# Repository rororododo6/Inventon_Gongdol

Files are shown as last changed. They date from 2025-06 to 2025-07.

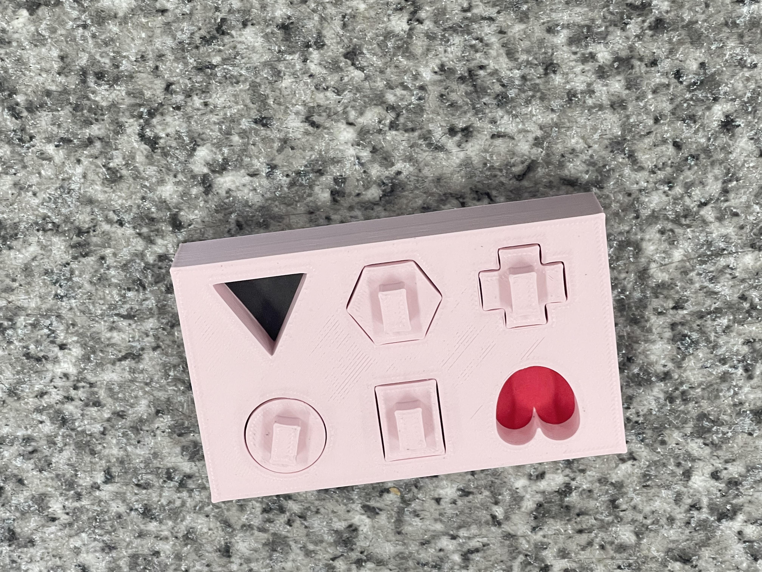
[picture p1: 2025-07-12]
HW/puzzle/AI/my-project/Parrot Puzzle.v2i.yolov11/test/images/KakaoTalk_20250710_180313041_14_jpg.rf.926b0de10124c375c126a7784142336b.jpg

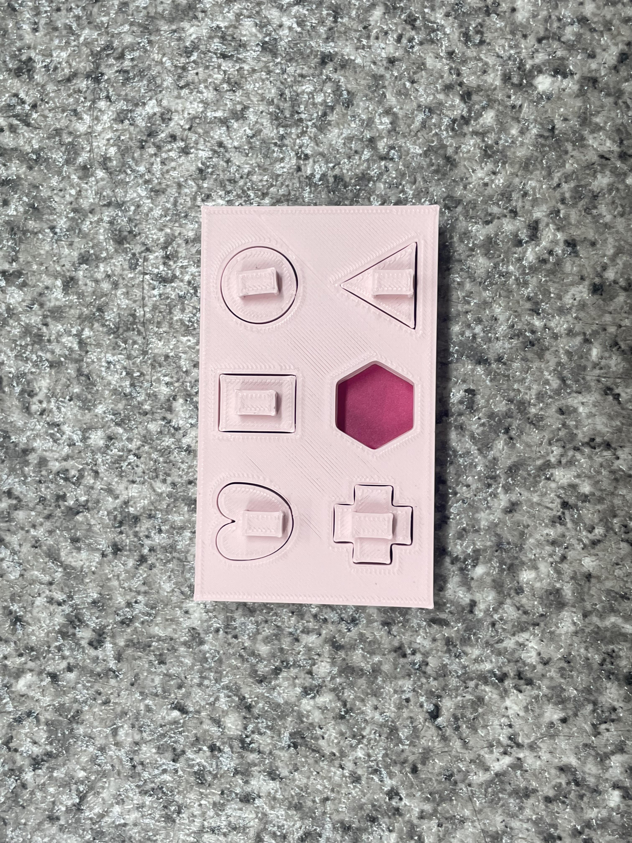
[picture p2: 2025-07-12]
HW/puzzle/AI/my-project/Parrot Puzzle.v2i.yolov11/test/images/KakaoTalk_20250710_180337943_19_jpg.rf.0f06c9184ed237936c7adf1d38ee5073.jpg

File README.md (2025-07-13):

# �� 새장 화장실 자동 청소 시스템

**라즈베리파이 4 + Arduino 기반 AI 새똥 탐지 및 자동 청소 시스템**

YOLO 커스텀 모델을 이용한 새똥 특화 탐지와 누적 방식 청소 시스템입니다.

## 🎯 주요 기능

### 🔍 AI 새똥 탐지 (누적 방식)
- **YOLO 커스텀 모델**: 새똥 특화 훈련 모델 (train63/weights/best.pt)
- **누적 탐지**: 새똥 영역을 메모리에 누적 저장
- **중복 제거**: IoU 계산으로 겹치는 영역 자동 병합
- **임계값**: 카메라 픽셀 면적의 **50%** 누적 시 청소 시작

### 🧹 3단계 자동 청소 시스템
- **1단계**: SG90 서보모터 모래 밀어내기 (0°↔90°, 20회)
- **2단계**: 28BYJ-48 스테핑 모터 똥 치우기 (3바퀴 회전)
- **3단계**: 원위치 복귀 및 누적 영역 데이터 초기화

### 🗑️ 스마트 청소 관리
- **청소 카운터**: 최대 100회 청소 제한
- **상태 모니터링**: 실시간 누적 영역 개수, 커버리지 비율 표시
- **경고 시스템**: 30%, 50% 임계값별 알림
- **안전 시스템**: 긴급 정지 버튼, 상태 LED, 알림 부저

### 📊 실시간 모니터링
- **환경 데이터**: DHT11 온습도 센서
- **시스템 상태**: 청소 횟수, 모터 상태, 메모리 사용량
- **성능 지표**: 탐지 정확도, 청소 성공률, FPS

## 🛠️ 하드웨어 구성

### 라즈베리파이 4
- **카메라**: PI 카메라 모듈 v2/v3 (640x480 권장)
- **UART 통신**: GPIO 14(TXD), GPIO 15(RXD) ↔ Arduino
- **운영체제**: Raspberry Pi OS
- **메모리**: 4GB 이상 권장

### Arduino Uno
- **DHT11 센서**: 핀 2번 (온습도 측정)
- **28BYJ-48 스테핑 모터**: 핀 5-8번 (ULN2003 드라이버)
- **SG90 서보모터**: 핀 9번 (모래 밀어내기)
- **긴급 정지 버튼**: 핀 3번 (인터럽트)
- **상태 LED**: 핀 13번
- **부저**: 핀 11번
- **UART 통신**: 115200 baud

> 📖 **상세 하드웨어 가이드**: [`HW/Toilet/Arduino/HARDWARE_CONNECTION.md`](HW/Toilet/Arduino/HARDWARE_CONNECTION.md)

## 🚀 빠른 시작

### 1. 환경 설정
```bash
# 프로젝트 루트로 이동
cd /home/parrot1/gongdol/Inventon_Gongdol

# uv 사용 환경 설정 (권장)
source $HOME/.local/bin/env
```

### 2. 라즈베리파이 시스템 실행
```bash
# 라즈베리파이 디렉토리로 이동
cd HW/Toilet/Raspberrypi

# 클린 버전 실행 (권장)
uv run clean-system

# 또는 Makefile 사용
make run                # 일반 실행
make run-headless      # SSH 접속 시
make run-test          # 테스트 모드
```

### 3. Arduino 펌웨어 업로드
```bash
# Arduino 디렉토리로 이동
cd HW/Toilet/Arduino

# PlatformIO 사용
platformio run --target upload

# 또는 Arduino IDE 사용
# src/main.cpp 파일 열기 → 업로드
```

> 📖 **상세 설치 가이드**: 
> - 라즈베리파이: [`HW/Toilet/Raspberrypi/README.md`](HW/Toilet/Raspberrypi/README.md)
> - Arduino: [`HW/Toilet/Arduino/README.md`](HW/Toilet/Arduino/README.md)

## 📡 통신 프로토콜

### 라즈베리파이 → Arduino
```json
{"command": "cage_cleaning"}              // 전체 청소 실행
{"command": "get_sensor_data"}            // 센서 데이터 요청
{"command": "emergency_reset"}            // 긴급 정지 해제
```

### Arduino → 라즈베리파이
```json
{
  "temperature": 25.5,
  "humidity": 60.2,
  "stepPosition": 0,
  "stepperRunning": false,
  "cleaning_cycles": 3,
  "emergency_stop": false,
  "timestamp": 1234567890
}
```

## 🔄 시스템 동작 흐름

1. **새똥 탐지** → YOLO 커스텀 모델로 실시간 탐지
2. **영역 누적** → 탐지된 영역을 메모리에 누적 저장
3. **중복 제거** → IoU > 10% 겹치는 영역 자동 병합
4. **임계값 확인** → 누적 커버리지 50% 도달 시 청소 시작
5. **3단계 청소** → 서보모터 → 스테핑 모터 → 원위치 복귀
6. **데이터 초기화** → 누적 영역 데이터 완전 삭제

## 📊 성능 지표

### 라즈베리파이 4 기준
- **커스텀 새똥 모델**: 3-6 FPS, 98% 이상 탐지 정확도
- **메모리 사용량**: 2.5-3.5GB
- **청소 성공률**: 95% 이상
- **응답 시간**: 탐지 → 청소 시작까지 < 2초

### 자동 최적화 기능
- 메모리 부족 시 모델 자동 전환 (YOLOv11n/s)
- 해상도 동적 조정 (640x480 ↔ 320x240)
- CPU 온도 모니터링 및 성능 조절

## 📂 프로젝트 구조

```
Inventon_Gongdol/
├── HW/Toilet/                    # 하드웨어 구현
│   ├── Raspberrypi/             # 라즈베리파이 시스템
│   │   ├── clean_ver/           # 최신 클린코딩 버전 (권장)
│   │   ├── main.py              # 메뉴 기반 런처
│   │   └── README.md            # 라즈베리파이 상세 가이드
│   └── Arduino/                 # Arduino 펌웨어
│       ├── src/main.cpp         # 메인 펌웨어
│       ├── platformio.ini       # PlatformIO 설정
│       └── README.md            # Arduino 상세 가이드
├── AI/detect/train63/           # YOLO 커스텀 모델
│   └── weights/best.pt          # 새똥 특화 훈련 모델
├── Design/                      # 설계 문서
└── README.md                    # 이 파일
```

## 🎮 사용법

### 키보드 제어
- **q**: 시스템 종료
- **r**: 시스템 리셋 (청소 후)
- **s**: 현재 상태 확인
- **SPACE**: 수동 청소 실행

### 상태 메시지 예시
```
[14:30:15] === 시스템 상태 ===
상태: 정상 작동
청소 횟수: 3/100
누적 새똥 영역: 2개
누적 커버리지: 35.2% (임계값: 50%)
⚠️ 주의: 누적 커버리지가 30%를 초과했습니다.
```

## 🔧 문제 해결

### 일반적인 문제
- **카메라 인식 안됨**: `sudo raspi-config` → Interface Options → Camera 활성화
- **권한 오류**: `sudo usermod -a -G video,dialout,gpio $USER`
- **시리얼 통신 안됨**: Arduino 펌웨어 업로드 및 포트 확인

### 성능 최적화
- **메모리 부족**: `make run-headless` 사용
- **낮은 FPS**: 해상도 640x480으로 조정
- **CPU 과열**: 방열판 설치 및 통풍 개선

> 📖 **상세 문제 해결 가이드**: 각 하위 폴더의 README.md 참조

## 🚀 최신 업데이트 (v2.0.0)

### ✅ 완료된 기능
- 누적 탐지 방식 구현
- 50% 임계값 자동 청소
- 3단계 청소 시스템
- 실시간 상태 모니터링
- 안전 시스템 (긴급 정지, LED, 부저)
- uv 패키지 관리자 지원

### 🔄 개발 진행 상황
- [x] 각 기능 유닛 테스트 완료
- [ ] 라즈베리파이 ↔ Arduino 통합 테스트
- [ ] 시리얼 통신 안정성 테스트
- [ ] 실제 새장 환경 E2E 테스트

## 📞 문의 및 기여

- **개발자**: rororododo6
- **저장소**: https://github.com/rororododo6/Inventon_Gongdol
- **문의**: GitHub Issues

---

**🎯 프로젝트 목표**: 새똥 탐지 정확도 98% 이상, 청소 성공률 95% 이상 달성  
**🛠️ 개발 환경**: Raspberry Pi OS, Arduino IDE, PlatformIO, Python 3.9+

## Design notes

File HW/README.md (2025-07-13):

# Inventon_Gongdol 🐦

라즈베리파이4 기반 새장 화장실 자동 청소 시스템 및 AI 퍼즐 프로젝트

## 📋 프로젝트 구조

```
Inventon_Gongdol/
├── AI/                     # AI 관련 모듈
│   ├── puzzle/            # 퍼즐 YOLO 모델
│   └── Toilet/            # 화장실 새똥 탐지 모델
├── HW/                    # 하드웨어 관련 모듈
│   ├── puzzle/            # 퍼즐 하드웨어
│   └── Toilet/            # 화장실 하드웨어
│       ├── Arduino/       # 아두이노 코드
│       └── Raspberrypi/   # 라즈베리파이 코드
├── Design/                # 설계 문서
├── uart_test.py          # UART 통신 테스트 스크립트
└── README.md             # 프로젝트 설명서
```

## 🎯 주요 기능

### 🚽 화장실 청소 시스템
- **AI 새똥 탐지**: YOLO 모델을 이용한 실시간 새똥 인식
- **자동 청소**: 360도 서보모터 MG996R을 이용한 자동 청소 메커니즘
- **UART 통신**: 라즈베리파이 ↔ 아두이노 간 GPIO 14,15 통신
- **실시간 모니터링**: 카메라 영상 및 시스템 상태 모니터링

### 🧩 퍼즐 시스템
- **퍼즐 인식**: YOLO 모델을 이용한 퍼즐 조각 인식
- **AI 훈련**: 커스텀 데이터셋을 이용한 모델 훈련

## 🛠️ 하드웨어 요구사항

### 라즈베리파이4 구성
- **메인 보드**: Raspberry Pi 4 Model B
- **카메라**: Pi Camera Module (libcamera 지원)
- **시리얼 통신**: GPIO 14 (TXD), GPIO 15 (RXD)
- **레벨 로직 컨버터**: 3.3V ↔ 5V 변환 (아두이노 통신용)

### 아두이노 구성
- **아두이노 보드**: Arduino Uno/Nano (또는 호환 보드)
- **360도 서보모터**: MG996R (청소 메커니즘)
- **DHT11 센서**: 온습도 모니터링
- **시리얼 통신**: RX, TX 핀 (레벨 로직 컨버터 경유)

### 청소 메커니즘
- **서보모터**: MG996R 360도 연속 회전 서보모터
- **청소 동작**: 앞으로 3초 → 뒤로 3초 → 정지
- **제어 방식**: PWM 신호 (1700us: 앞으로, 1300us: 뒤로, 1500us: 정지)

## 🔧 소프트웨어 요구사항

### 시스템 요구사항
- **OS**: Raspberry Pi OS (Debian 기반)
- **Python**: 3.11 이상
- **패키지 매니저**: uv (권장)

### 주요 라이브러리
- **AI/비전**: `ultralytics`, `torch`, `torchvision`, `opencv-python`
- **카메라**: `picamera2`, `libcamera`
- **시리얼 통신**: `pyserial`
- **기타**: `numpy`, `matplotlib`, `pyyaml`

### 아두이노 라이브러리
- **ArduinoJson**: JSON 통신 처리
- **DHT sensor library**: 온습도 센서
- **Servo**: 360도 서보모터 제어

## 🚀 설치 및 실행

### 1. 시스템 패키지 설치
```bash
# 시스템 업데이트
sudo apt update && sudo apt upgrade -y

# 필수 패키지 설치
sudo apt install -y \
    python3-pip python3-venv python3-dev \
    python3-picamera2 libcamera-apps v4l-utils \
    build-essential cmake pkg-config \
    libjpeg-dev libtiff5-dev libpng-dev \
    libavcodec-dev libavformat-dev libswscale-dev \
    libv4l-dev libxvidcore-dev libx264-dev \
    libgtk-3-dev libatlas-base-dev gfortran \
    libcap-dev git curl
```

### 2. uv 패키지 매니저 설치
```bash
curl -LsSf https://astral.sh/uv/install.sh | sh
source $HOME/.local/bin/env
```

### 3. 프로젝트 환경 설정
```bash
# 프로젝트 클론 (이미 있는 경우 생략)
git clone <repository-url>
cd Inventon_Gongdol

# Python 가상 환경 생성
uv venv --python 3.11 .venv

# 가상 환경 활성화
source .venv/bin/activate

# 의존성 설치
cd HW/Toilet/Raspberrypi
uv pip install -e .
```

### 4. 시스템 권한 설정
```bash
# 시리얼 포트 접근 권한 추가
sudo usermod -a -G dialout $USER

# 재부팅 후 권한 적용
sudo reboot
```

## 📱 실행 방법

### 환경 활성화
```bash
cd /home/parrot1/gongdol/Inventon_Gongdol
source $HOME/.local/bin/env
source .venv/bin/activate
```

### 시스템 실행
```bash
cd HW/Toilet/Raspberrypi
python main.py
```

### UART 통신 테스트
```bash
# 프로젝트 루트에서
python uart_test.py
```

## 🔌 하드웨어 연결

### UART 시리얼 통신 연결
```
라즈베리파이4          레벨 로직 컨버터          아두이노
GPIO 14 (TXD) ──────→ 3.3V → 5V ──────→ RX 핀
GPIO 15 (RXD) ──────← 5V → 3.3V ──────← TX 핀
GND ─────────────────────────────────────── GND
```

### 360도 서보모터 연결
```
아두이노              MG996R 서보모터
Digital Pin 9 ──────→ 신호선 (주황/노랑)
5V ─────────────────→ 전원선 (빨강)
GND ────────────────→ 접지선 (갈색/검정)
```

### 통신 설정
- **포트**: `/dev/serial0`
- **보드레이트**: 115200
- **데이터 비트**: 8
- **패리티**: None
- **스톱 비트**: 1

## 🎮 시스템 사용법

### 1. 화장실 청소 시스템
```bash
# 시스템 실행
python main.py

# 메뉴에서 "1. PI 카메라 클라이언트 실행" 선택
# - 실시간 새똥 탐지 시작
# - 자동 청소 기능 활성화
# - UART 통신을 통한 아두이노 제어
```

### 2. 청소 동작 과정
1. **탐지**: 카메라로 새똥 영역 탐지 (커버리지 3% 이상)
2. **청소 시작**: 360도 서보모터 앞으로 3초 회전
3. **역방향 청소**: 뒤로 3초 회전으로 완전 청소
4. **정지**: 서보모터 정지 후 대기 상태

### 3. 상태 모니터링
- **탐지 상태**: 실시간 새똥 탐지 결과 및 커버리지
- **청소 카운트**: 자동 청소 실행 횟수
- **시스템 상태**: 온도, 습도 센서 정보
- **서보모터 상태**: 회전 방향 및 작동 상태

## 🔧 아두이노 통신 프로토콜

### 명령어 목록
```json
// 센서 데이터 요청
{"command": "get_sensor_data"}

// 서보모터 제어
{"command": "control_servo", "direction": 1}  // 1: 앞으로, -1: 뒤로, 0: 정지

// 서보모터 정지
{"command": "stop_servo"}

// 자동 청소 실행
{"command": "cage_cleaning"}

// 시스템 상태 확인
{"command": "get_status"}
```

### 응답 형식
```json
// 센서 데이터 응답
{
  "type": "sensor_data",
  "temp": 25.5,
  "hum": 60.2,
  "servo_run": true,
  "servo_dir": 1,
  "time": 123456
}

// 상태 정보 응답
{
  "type": "status",
  "ver": "1.3.1",
  "servo_run": false,
  "servo_dir": 0,
  "cycles": 5,
  "max": 100
}
```

## 🔧 개발 및 디버깅

### 로그 확인
```bash
# 시스템 로그 확인
tail -f detection_log.txt

# 아두이노 시리얼 모니터
sudo minicom -D /dev/serial0 -b 115200
```

### 모델 훈련 (AI 모듈)
```bash
# 퍼즐 모델 훈련
cd AI/puzzle
python main.py

# 화장실 모델 훈련
cd AI/Toilet
python calculate_area.py
```

### 서보모터 테스트
```bash
# 아두이노 시리얼 모니터에서 직접 명령 테스트
{"command": "control_servo", "direction": 1}
{"command": "control_servo", "direction": -1}
{"command": "stop_servo"}
```

## 📝 주요 파일 설명

### HW/Toilet/Raspberrypi/
- **`main.py`**: 시스템 메인 런처
- **`pi_camera_client.py`**: 카메라 및 AI 모델 처리
- **`raspberry_pi_client.py`**: 시스템 통합 모듈
- **`test_imports.py`**: 라이브러리 import 테스트

### HW/Toilet/Arduino/
- **`main.cpp`**: 아두이노 메인 코드
- **`functions.h`**: 함수 헤더 파일

### AI/
- **`puzzle/main.py`**: 퍼즐 YOLO 모델 훈련
- **`Toilet/calculate_area.py`**: 새똥 면적 계산 모듈

### 설정 파일
- **`pyproject.toml`**: Python 프로젝트 의존성 관리
- **`uart_test.py`**: UART 통신 테스트 스크립트

## 🚨 문제 해결

### 카메라 관련 오류
```bash
# 카메라 활성화 확인
sudo raspi-config
# Interface Options → Camera → Enable

# 카메라 연결 확인
libcamera-hello --list-cameras
```

### 시리얼 통신 오류
```bash
# 시리얼 포트 확인
ls -la /dev/serial*
ls -la /dev/ttyS*

# 권한 확인
groups $USER  # dialout 그룹 포함 확인
```

### 서보모터 문제
```bash
# 서보모터 연결 확인
# 1. 전원 연결 (5V, GND)
# 2. 신호선 연결 (Digital Pin 9)
# 3. 서보모터 동작 테스트

# 아두이노 시리얼 모니터에서 테스트
{"command": "system_test"}
```

### 라이브러리 import 오류
```bash
# 테스트 실행
python test_imports.py

# 누락된 라이브러리 개별 설치
uv pip install <library-name>
```

## ⚙️ 하드웨어 사양

### MG996R 서보모터 사양
- **토크**: 11kg·cm (4.8V), 13kg·cm (6V)
- **속도**: 0.17초/60° (4.8V), 0.14초/60° (6V)
- **제어 신호**: PWM (20ms 주기)
- **전원**: 4.8V ~ 7.2V
- **무게**: 55g

### 청소 메커니즘 특징
- **연속 회전**: 360도 무제한 회전 가능
- **양방향 제어**: 시계/반시계 방향 제어
- **정밀한 정지**: 1500us 신호로 정확한 정지
- **내구성**: 고토크로 안정적인 청소 작업

## 🤝 기여

프로젝트에 기여하고 싶으시다면:
1. Fork 후 Pull Request 생성
2. 이슈 등록 및 버그 리포트
3. 기능 개선 제안

## 📄 라이선스

MIT License - 자세한 내용은 LICENSE 파일 참조

## 📞 연락처

프로젝트 관련 문의사항이 있으시면 이슈를 등록해주세요.

---

**🍓 Made with ❤️ on Raspberry Pi 4 + MG996R Servo Motor**

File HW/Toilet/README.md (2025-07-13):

# 🧹 새장 화장실 자동 청소 시스템 - 하드웨어 구현

**라즈베리파이 4 + Arduino Uno 기반 하드웨어 제어 시스템**

AI 새똥 탐지 시스템과 연동되는 하드웨어 구현 부분입니다.

## 📂 하드웨어 구조

```
HW/Toilet/
├── Raspberrypi/              # 🍓 라즈베리파이 시스템
│   ├── clean_ver/           # 최신 클린코딩 버전 (권장)
│   ├── main.py              # 메뉴 기반 런처
│   └── README.md            # 라즈베리파이 상세 가이드
├── Arduino/                 # 🔧 Arduino 펌웨어
│   ├── src/main.cpp         # 메인 펌웨어 (v1.3.1)
│   ├── platformio.ini       # PlatformIO 설정
│   └── README.md            # Arduino 상세 가이드
├── Layout/                  # 📐 하드웨어 레이아웃
└── README.md                # 이 파일
```

## 🔗 시스템 연동 구조

```
┌─────────────────────────────────────────────────────────────────┐
│                    라즈베리파이 4 (메인 시스템)                    │
├─────────────────────────────────────────────────────────────────┤
│ • AI 새똥 탐지 (YOLO 커스텀 모델)                               │
│ • 누적 영역 관리 (50% 임계값)                                   │
│ • 카메라 제어 (640x480)                                        │
│ • 시스템 모니터링                                              │
└─────────────────────┬───────────────────────────────────────────┘
                      │ UART 통신 (115200 baud)
                      │ GPIO 14(TXD) ↔ GPIO 15(RXD)
┌─────────────────────▼───────────────────────────────────────────┐
│                   Arduino Uno (하드웨어 제어)                   │
├─────────────────────────────────────────────────────────────────┤
│ • 환경 모니터링 (DHT11 온습도)                                  │
│ • 3단계 청소 시스템                                            │
│ • 안전 시스템 (긴급 정지, LED, 부저)                           │
│ • 모터 제어 (서보 + 스테핑)                                    │
└─────────────────────────────────────────────────────────────────┘
```

## 🛠️ 하드웨어 구성

### 라즈베리파이 4 (메인 시스템)
- **모델**: Raspberry Pi 4B (4GB 이상 권장)
- **카메라**: PI 카메라 모듈 v2/v3
- **해상도**: 640x480 (최적화됨)
- **통신**: UART (GPIO 14/15)
- **성능**: 3-6 FPS, 98% 탐지 정확도

### Arduino Uno (하드웨어 제어)
- **모델**: Arduino Uno R3
- **펌웨어**: v1.3.1 (클린코딩 버전)
- **통신**: 시리얼 (115200 baud)
- **제어**: 온습도 센서, 서보모터, 스테핑 모터

### 센서 및 액추에이터
| 부품 | 모델 | 핀 번호 | 기능 |
|---|---|---|---|
| 온습도 센서 | DHT11 | D2 | 환경 모니터링 |
| 서보모터 | SG90 | D9 | 모래 밀어내기 |
| 스테핑 모터 | 28BYJ-48 | D5-D8 | 똥 치우기 |
| 드라이버 보드 | ULN2003 | D5-D8 | 스테핑 모터 제어 |
| 긴급 정지 버튼 | 푸시 버튼 | D3 | 안전 시스템 |
| 상태 LED | 5mm LED | D13 | 시스템 상태 표시 |
| 부저 | 액티브 부저 | D11 | 알림음 |

## 🔄 3단계 청소 프로세스

### 1단계: 모래 밀어내기 (서보모터)
```
SG90 서보모터 제어
├── 0° → 90° → 0° (20회 반복)
├── 소요시간: 약 20초
└── 목적: 새똥 위 모래 제거
```

### 2단계: 똥 치우기 (스테핑 모터)
```
28BYJ-48 스테핑 모터 제어
├── 전진: 3바퀴 회전 (6144 스텝)
├── 대기: 1초
├── 후진: 원위치 복귀 (-6144 스텝)
└── 목적: 새똥 수집 및 제거
```

### 3단계: 시스템 초기화
```
소프트웨어 초기화
├── 누적 탐지 영역 데이터 삭제
├── 청소 카운터 증가
└── 시스템 상태 리셋
```

## 📡 통신 프로토콜

### 라즈베리파이 → Arduino (명령)
```json
{"command": "cage_cleaning"}          // 전체 청소 실행
{"command": "get_sensor_data"}        // 센서 데이터 요청
{"command": "cleaning_servo"}         // 서보모터만 실행
{"command": "stepper_move", "value": 2048}  // 스테핑 모터 이동
{"command": "emergency_reset"}        // 긴급 정지 해제
```

### Arduino → 라즈베리파이 (응답)
```json
{
  "temperature": 25.5,
  "humidity": 60.2,
  "stepPosition": 0,
  "stepperRunning": false,
  "cleaning_cycles": 3,
  "emergency_stop": false,
  "timestamp": 1234567890
}
```

## 🚀 빠른 시작

### 1. 라즈베리파이 시스템 실행
```bash
cd Raspberrypi/
uv run clean-system              # 권장
# 또는
make run-headless               # SSH 접속 시
```

### 2. Arduino 펌웨어 업로드
```bash
cd Arduino/
platformio run --target upload
# 또는 Arduino IDE 사용
```

### 3. 하드웨어 연결 확인
```bash
# 라즈베리파이에서 시리얼 통신 테스트
cd Raspberrypi/
python uart_test.py
```

## 🔧 하드웨어 설정

### 전원 공급
- **라즈베리파이**: 5V 3A 어댑터 (USB-C)
- **Arduino**: USB 전원 또는 DC 7-12V
- **서보모터**: 5V (Arduino 5V 핀)
- **스테핑 모터**: 5V (ULN2003 보드)

### 배선 가이드
```
라즈베리파이 → Arduino
├── GPIO 14 (TXD) → Arduino RX (D0)
├── GPIO 15 (RXD) → Arduino TX (D1)
└── GND → GND (공통 접지)

Arduino → 센서/액추에이터
├── D2 → DHT11 데이터 핀
├── D3 → 긴급 정지 버튼
├── D5-D8 → ULN2003 IN1-IN4
├── D9 → SG90 서보모터 신호선
├── D11 → 부저 양극
└── D13 → LED 양극
```

> 📖 **상세 배선 가이드**: [`Arduino/HARDWARE_CONNECTION.md`](Arduino/HARDWARE_CONNECTION.md)

## 📊 성능 지표

### 시스템 성능
- **탐지 정확도**: 98% 이상 (커스텀 모델)
- **청소 성공률**: 95% 이상
- **응답 시간**: 탐지 → 청소 시작 < 2초
- **처리 속도**: 3-6 FPS (640x480 해상도)

### 하드웨어 성능
- **서보모터**: 0° ↔ 90° 이동 시간 0.5초
- **스테핑 모터**: 12 RPM 청소 속도
- **센서 업데이트**: 3초마다 자동 전송
- **통신 속도**: 115200 baud 안정적

## 🔍 문제 해결

### 일반적인 문제
- **시리얼 통신 안됨**: 케이블 연결 및 포트 확인
- **서보모터 작동 안됨**: 전원 공급 및 신호선 확인
- **스테핑 모터 떨림**: ULN2003 보드 전원 확인
- **센서 데이터 오류**: DHT11 연결 및 라이브러리 확인

### 성능 최적화
- **통신 지연**: 버퍼 크기 조정 (현재 512 bytes)
- **모터 속도**: 청소 품질 vs 속도 트레이드오프
- **메모리 사용**: Arduino 메모리 모니터링 (freeMemory() 함수)

## 📁 관련 문서

- **라즈베리파이 시스템**: [`Raspberrypi/README.md`](Raspberrypi/README.md)
- **Arduino 펌웨어**: [`Arduino/README.md`](Arduino/README.md)  
- **하드웨어 연결**: [`Arduino/HARDWARE_CONNECTION.md`](Arduino/HARDWARE_CONNECTION.md)
- **전체 프로젝트**: [`../../README.md`](../../README.md)

---

**🎯 하드웨어 목표**: 안정적이고 정확한 3단계 청소 시스템 구현  
**🔧 개발 환경**: Raspberry Pi OS, Arduino IDE, PlatformIO

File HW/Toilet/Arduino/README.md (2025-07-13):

# 🔧 새장 화장실 자동 청소 시스템 - Arduino 펌웨어

**Arduino Uno 기반 하드웨어 제어 펌웨어 v1.3.1**

라즈베리파이와 시리얼 통신으로 연동하여 3단계 청소를 위한 하드웨어를 제어하는 Arduino 펌웨어입니다.

> 📖 **전체 프로젝트 개요**: [`../../../README.md`](../../../README.md)  
> 📖 **하드웨어 전체 가이드**: [`../README.md`](../README.md)  
> 📖 **라즈베리파이 시스템**: [`../Raspberrypi/README.md`](../Raspberrypi/README.md)

## 🎯 주요 기능

### 🧹 3단계 청소 시스템
- **1단계**: SG90 서보모터 모래 밀어내기 (0°↔90°, 20회)
- **2단계**: 28BYJ-48 스테핑 모터 똥 치우기 (3바퀴 회전)
- **3단계**: 원위치 복귀 및 시스템 초기화

### 🤖 하드웨어 제어
- **🌡️ 환경 모니터링**: DHT11 온습도 센서 실시간 데이터 수집
- **🔄 정밀 모터 제어**: ULN2003 + 28BYJ-48 스테핑 모터 제어
- **🚨 안전 시스템**: 긴급 정지 버튼, 상태 LED, 알림 부저

### 📡 통신 시스템
- **실시간 통신**: 라즈베리파이와 115200 baud 시리얼 통신
- **JSON 프로토콜**: 구조화된 명령/응답 시스템
- **버퍼 관리**: 512 bytes 입력 버퍼

## 📂 프로젝트 구조

```
Arduino/
├── src/                     # 📁 소스 코드
│   └── main.cpp            # 🎯 메인 Arduino 펌웨어
├── include/                # 📁 헤더 파일
│   ├── README             # 헤더 폴더 설명
│   └── functions.h        # 🔧 함수 선언
├── lib/                   # 📁 라이브러리 폴더
├── platformio.ini         # ⚙️ PlatformIO 프로젝트 설정
├── requirements.txt       # 🐍 Python 요구사항 (라즈베리파이용)
├── HARDWARE_CONNECTION.md # 🔌 하드웨어 연결 가이드
└── README.md             # 📖 이 파일
```

## 🔌 하드웨어 구성

### Arduino 핀 배치
| 핀 번호 | 연결 부품 | 기능 |
|---|---|---|
| **2** | DHT11 센서 | 온습도 측정 |
| **3** | 긴급 정지 버튼 | 안전 정지 (인터럽트) |
| **5** | ULN2003 IN1 | 스테핑 모터 제어 |
| **6** | ULN2003 IN2 | 스테핑 모터 제어 |
| **7** | ULN2003 IN3 | 스테핑 모터 제어 |
| **8** | ULN2003 IN4 | 스테핑 모터 제어 |
| **9** | SG90 서보모터 | 모래 밀어내기 |
| **11** | 부저 | 상태 알림음 |
| **13** | 상태 LED | 시스템 상태 표시 |

### 필수 부품 리스트
- **Arduino Uno** (메인 제어 보드)
- **DHT11 온습도 센서**
- **28BYJ-48 스테핑 모터 + ULN2003 드라이버 보드**
- **SG90 서보모터** (청소용)
- **긴급 정지 푸시 버튼**
- **5mm LED** (상태 표시용)
- **부저** (알림음용)
- **점퍼 와이어 및 브레드보드**

## 🚀 설치 및 업로드

### 1. PlatformIO 설치 (권장)
```bash
# PlatformIO CLI 설치
pip install platformio

# 또는 VS Code에서 PlatformIO IDE 확장 설치
```

### 2. 라이브러리 의존성
`platformio.ini`에서 자동 설치됩니다:
- **ArduinoJson** v7.0.0: JSON 통신
- **AccelStepper** v1.64: 스테핑 모터 제어
- **Servo** v1.2.1: 서보모터 제어  
- **DHT sensor library** v1.4.4: 온습도 센서
- **Stepper** v1.1.3: 기본 스테핑 모터

### 3. 펌웨어 업로드
```bash
# 프로젝트 빌드 및 업로드
platformio run --target upload

# 시리얼 모니터 실행
platformio device monitor

# 또는 Arduino IDE 사용
# File → Open → Arduino 폴더 선택
# Tools → Board → Arduino Uno
# Sketch → Upload
```

## 🎮 청소 시스템 동작

### 3단계 청소 프로세스
```
1️⃣ 서보모터 작동 (모래 밀어내기)
   ├── 0° → 90° → 0° (20회 반복)
   └── 소요시간: 약 20초

2️⃣ 대기 시간 (안정화)
   └── 1초 대기

3️⃣ 스테핑 모터 작동 (똥 치우기)
   ├── 앞으로 3바퀴 회전 (6144 스텝)
   ├── 1초 대기
   └── 원위치 복귀 (-6144 스텝)
```

### 시스템 상태 관리
- **정상 상태**: 청소 명령 수행 가능
- **긴급 정지**: 모든 모터 즉시 정지
- **청소 카운터**: 최대 100회 청소 제한
- **에러 처리**: 센서 오류 시 기본값 반환

## 📡 통신 프로토콜

### 시리얼 통신 설정
- **Baud Rate**: 115200
- **Data Bits**: 8
- **Stop Bits**: 1
- **Parity**: None
- **Buffer Size**: 512 bytes

### JSON 명령어 형식
```json
{
  "command": "명령어_타입",
  "value": 매개변수_값
}
```

### 지원 명령어 목록

#### 🌡️ 센서 데이터
```json
// 온습도 데이터 요청
{"command": "get_sensor_data"}

// 응답 예시
{
  "temperature": 23.5,
  "humidity": 58.0,
  "stepPosition": 0,
  "stepperSpeed": 10,
  "stepperRunning": false,
  "timestamp": 12345678
}
```

#### 💡 LED 제어
```json
{"command": "led_on"}     // LED 켜기
{"command": "led_off"}    // LED 끄기
```

#### 🔄 스테핑 모터 제어
```json
{"command": "stepper_move", "value": 2048}    // 2048스텝 이동
{"command": "stepper_speed", "value": 15}     // 속도 15 RPM 설정
{"command": "stepper_stop"}                   // 모터 정지
{"command": "stepper_reset"}                  // 위치 초기화
{"command": "stepper_disable"}                // 모터 비활성화
```

#### 🧹 청소 시스템
```json
{"command": "cage_cleaning"}        // 전체 청소 프로세스 실행
{"command": "cleaning_servo"}       // 서보모터만 작동
{"command": "reset_cleaning_cycles"} // 청소 횟수 초기화
```

#### 🚨 안전 시스템
```json
{"command": "emergency_reset"}      // 긴급 정지 해제
{"command": "system_test"}          // 하드웨어 테스트
```

### 상태 메시지
```json
// 시스템 상태 정보
{
  "status": "ready",
  "emergency_stop": false,
  "cleaning_cycles": 5,
  "cleaning_servo_active": false,
  "last_cleaning": 1234567890,
  "free_memory": 1234
}
```

## 🔧 설정 및 튜닝

### 모터 설정 상수
```cpp
// 스테핑 모터 설정
const byte DEFAULT_SPEED = 10;        // 기본 속도 (RPM)
const byte CLEANING_SPEED = 12;       // 청소 속도 (RPM)
const int CLEANING_ROTATIONS = 3;     // 청소 시 회전 수
const int CLEANING_DELAY = 1000;      // 청소 단계 간 대기

// 서보모터 설정
const int SERVO_90_PULSE = 1500;      // 90도 PWM 신호
const int SERVO_0_PULSE = 1000;       // 0도 PWM 신호
const byte SERVO_REPEAT_COUNT = 20;   // 반복 횟수
const int SERVO_HOLD_TIME = 1000;     // 위치 유지 시간
```

### 센서 설정
```cpp
const unsigned long SENSOR_UPDATE_INTERVAL = 3000;  // 3초마다 자동 전송
const unsigned long EMERGENCY_REPORT_INTERVAL = 5000; // 긴급 상태 5초마다 보고
```

## 🎵 부저 및 LED 신호

### 시작 신호
- **LED**: 3회 깜빡임
- **부저**: 1000Hz, 200ms

### 청소 완료 신호
- **부저**: 1200Hz, 300ms

### 시스템 테스트 신호
- **LED**: 2회 깜빡임
- **부저**: 800Hz → 1200Hz (각 100ms)

## 🔍 문제 해결

### 일반적인 문제

#### 1. 업로드 실패
```bash
# 포트 확인
ls /dev/ttyUSB* /dev/ttyACM*

# 권한 설정
sudo usermod -a -G dialout $USER

# 다른 프로그램에서 포트 사용 중이면 종료
sudo lsof | grep ttyUSB
```

#### 2. 시리얼 통신 안됨
```cpp
// 시리얼 모니터에서 확인
Arduino Ready for Raspberry Pi Communication
DHT11 Sensor and ULN2003 Stepper Motor Control Available
Bird Cage Toilet Cleaning System Enabled
Emergency Stop System Active
```

#### 3. DHT11 센서 오류
- 연결 확인: VCC(5V), DATA(2번핀), GND
- 센서 교체 고려
- 에러 시 기본값(-999) 반환

#### 4. 스테핑 모터 작동 안됨
- ULN2003 전원 연결 확인 (5V)
- 핀 연결 확인: IN1(5), IN2(6), IN3(7), IN4(8)
- 모터와 드라이버 연결 확인

#### 5. 서보모터 작동 안됨  
- 전원 확인 (5V)
- 신호선 연결 확인 (9번 핀)
- PWM 신호 확인

### 디버깅 방법

#### 시리얼 모니터 활용
```bash
# PlatformIO 시리얼 모니터
platformio device monitor

# 또는 screen 사용
screen /dev/ttyUSB0 115200
```

#### 메모리 사용량 확인
```json
{"command": "get_sensor_data"}
// 응답에서 free_memory 값 확인
```

#### 시스템 테스트
```json
{"command": "system_test"}
// LED 깜빡임과 부저음으로 하드웨어 상태 확인
```

## 📊 성능 정보

### 메모리 사용량
- **프로그램 메모리**: ~15KB / 32KB
- **SRAM**: ~1.2KB / 2KB  
- **여유 SRAM**: ~800 bytes

### 응답 시간
- **센서 데이터**: ~10ms
- **LED 제어**: ~1ms
- **스테핑 모터**: ~5ms (명령 수신)
- **전체 청소**: ~45초

### 전력 소비
- **대기 상태**: ~150mA
- **청소 중**: ~600mA (스테핑 모터 작동 시)

## 🔄 업데이트 및 유지보수

### 정기 점검 사항
1. **하드웨어 연결 상태** (주 1회)
2. **센서 정확도 확인** (월 1회)  
3. **모터 동작 점검** (월 1회)
4. **긴급 정지 버튼 테스트** (월 1회)

### 펌웨어 업데이트
```bash
# 최신 코드 받기
git pull origin main

# 빌드 및 업로드
platformio run --target upload
```

### 백업 및 복원
```bash
# 설정 백업
cp platformio.ini platformio.ini.backup

# 펌웨어 백업 (hex 파일)
cp .pio/build/uno/firmware.hex firmware_backup.hex
```

## 🔗 관련 문서

- **하드웨어 연결**: `HARDWARE_CONNECTION.md`
- **라즈베리파이 코드**: `../Raspberrypi/`
- **전체 시스템**: `../README.md`
- **PlatformIO 문서**: https://docs.platformio.org/

## 🆕 버전 정보

### v1.3.1 (현재) - Bird Cage Toilet Cleaning System
- 새장 화장실 청소 시스템으로 완전 전환
- 3단계 청소 프로세스 구현
- JSON 기반 통신 프로토콜 안정화
- 긴급 정지 시스템 강화
- 메모리 최적화 및 성능 개선

### v1.2.0  
- YOLOv11s 연동 최적화
- 스테핑 모터 정밀도 향상
- DHT11 센서 안정성 개선

### v1.1.0
- 기본 청소 시스템 구현
- 시리얼 통신 프로토콜 확립

## 📁 관련 문서

- **라즈베리파이 시스템**: [`../Raspberrypi/README.md`](../Raspberrypi/README.md)
- **하드웨어 전체 가이드**: [`../README.md`](../README.md)
- **하드웨어 연결 가이드**: [`HARDWARE_CONNECTION.md`](HARDWARE_CONNECTION.md)
- **전체 프로젝트**: [`../../../README.md`](../../../README.md)

---

**🎯 Arduino 목표**: 안정적이고 정확한 3단계 청소 하드웨어 제어 시스템 구현  
**🛠️ 개발 환경**: Arduino IDE 1.8.19+, PlatformIO Core 6.0+

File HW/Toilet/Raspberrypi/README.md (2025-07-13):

# 🍓 새장 화장실 자동 청소 시스템 - 라즈베리파이

**라즈베리파이 4 기반 AI 새똥 탐지 및 시스템 제어**

YOLO 커스텀 모델을 이용한 새똥 누적 탐지와 Arduino 하드웨어 제어 시스템입니다.

> 📖 **전체 프로젝트 개요**: [`../../../README.md`](../../../README.md)  
> 📖 **하드웨어 전체 가이드**: [`../README.md`](../README.md)

## 🎯 주요 기능

### 🔍 AI 새똥 탐지 시스템
- **YOLO 커스텀 모델**: train63 데이터셋으로 훈련된 새똥 전용 모델
- **누적 탐지 방식**: 탐지된 영역을 메모리에 누적 저장
- **IoU 기반 병합**: 겹치는 영역 자동 제거 (IoU > 10%)
- **50% 임계값**: 누적 커버리지 50% 도달 시 자동 청소

### 🤖 Arduino 하드웨어 제어
- **UART 통신**: 115200 baud 시리얼 통신
- **JSON 프로토콜**: 구조화된 명령/응답 시스템
- **실시간 모니터링**: 온습도, 모터 상태, 청소 횟수
- **안전 시스템**: 긴급 정지, 상태 확인, 에러 처리

### 📊 성능 최적화
- **동적 해상도**: 640x480 ↔ 320x240 자동 조정
- **메모리 관리**: 모델 자동 전환 (커스텀 → YOLOv11n/s)
- **CPU 모니터링**: 온도 기반 성능 조절
- **헤드리스 모드**: SSH 접속 시 최적화

## 📂 프로젝트 구조

```
Raspberrypi/
├── clean_ver/                   # ✨ 최신 클린코딩 버전 (권장)
│   ├── run_system.py           # 메인 시스템 실행기
│   ├── pi_camera_client_clean.py  # 최적화된 카메라 클라이언트
│   ├── optimized_config.py     # 성능 최적화 설정
│   ├── main.py                 # 클린 버전 런처
│   ├── factories/              # 팩토리 패턴 구현
│   └── managers/               # 시스템 관리자들
├── main.py                     # 🚀 메뉴 기반 시스템 런처
├── pi_camera_client.py         # 📦 레거시 카메라 클라이언트
├── uart_test.py                # 🧪 시리얼 통신 테스트
├── quick-start.sh              # ⚡ 빠른 시작 스크립트
├── setup-env.sh                # 🔧 환경 설정 스크립트
├── Makefile                    # 📋 빌드 및 실행 관리
├── pyproject.toml              # 📦 Python 프로젝트 설정
└── README.md                   # 📖 이 파일
```

## 🚀 빠른 시작

### ⚡ 추천 실행 방법 (uv 사용)

```bash
# 1. 환경 설정
source $HOME/.local/bin/env

# 2. 클린 버전 실행 (최신 권장)
uv run clean-system

# 3. 헤드리스 모드 (SSH 접속 시)
uv run clean-system --headless

# 4. 테스트 모드 (하드웨어 없이)
uv run clean-system --test --headless
```

### 🎛️ Makefile 사용 (더 편리)

```bash
make run              # 일반 실행
make run-headless     # 헤드리스 모드 (SSH 권장)
make run-test         # 테스트 모드
make check            # 시스템 검사
make setup            # 의존성 설치
make help             # 도움말
```

### 📜 빠른 시작 스크립트

```bash
./quick-start.sh      # 대화형 빠른 시작
./setup-env.sh        # 전체 환경 설정
```

## 📋 버전 비교

### ✨ Clean Ver (권장)
- **위치**: `clean_ver/` 폴더
- **특징**: 최신 최적화 버전
- **성능**: 메모리 자동 최적화, 3-8 FPS
- **안정성**: 팩토리 패턴, 예외 처리 강화
- **모니터링**: 실시간 시스템 상태 표시
- **실행**: `uv run clean-system`

### 📦 Legacy Ver
- **위치**: 루트 폴더
- **특징**: 개발 초기 버전
- **용도**: 호환성 확인, 참고용
- **실행**: `python main.py`

## 🛠️ 설치 및 설정

### 🚀 자동 설치 (권장)

```bash
# 전체 환경 자동 설치
./setup-env.sh

# 또는 Makefile 사용
make install
```

### 🔧 수동 설치

#### 1. uv 패키지 관리자 설치
```bash
# uv 설치
curl -LsSf https://astral.sh/uv/install.sh | sh
source ~/.bashrc

# 프로젝트 의존성 설치
uv sync
```

#### 2. 시스템 패키지 설치
```bash
# 필수 시스템 패키지
sudo apt update && sudo apt install -y \
    python3-picamera2 libcamera-apps \
    python3-dev build-essential

# 카메라 활성화
sudo raspi-config
# 3 Interface Options → I1 Camera → Yes
sudo reboot
```

#### 3. 권한 설정
```bash
# 사용자 그룹 추가
sudo usermod -a -G video,dialout,gpio $USER

# 재로그인 또는 재부팅
sudo reboot
```

## 🎮 사용법

### 키보드 제어
- **q**: 시스템 종료
- **r**: 시스템 리셋 (청소 후)
- **s**: 현재 상태 확인
- **SPACE**: 수동 청소 실행
- **h**: 도움말 표시

### 실행 옵션
```bash
# 기본 실행
uv run clean-system

# 헤드리스 모드 (SSH 접속 시)
uv run clean-system --headless

# 테스트 모드 (하드웨어 없이)
uv run clean-system --test

# 디버그 모드
uv run clean-system --debug

# 커스텀 모델 사용
uv run clean-system --model /path/to/model.pt

# 신뢰도 임계값 변경
uv run clean-system --confidence 0.4
```

## 📊 성능 지표

### 라즈베리파이 4 기준
- **커스텀 새똥 모델**: 3-6 FPS, 98% 이상 탐지 정확도
- **YOLOv11s**: 3-5 FPS (4GB), 5-8 FPS (8GB)
- **YOLOv11n**: 5-10 FPS (자동 전환 시)
- **메모리 사용**: 2.5-3.5GB
- **응답 시간**: 탐지 → 청소 시작 < 2초

### 자동 최적화 기능
- **메모리 부족 시**: 모델 자동 전환 (커스텀 → YOLOv11n)
- **CPU 과열 시**: 해상도 자동 조정 (640x480 → 320x240)
- **성능 저하 시**: 프레임 스킵 및 버퍼 최적화

## 🔗 Arduino 연동

### 시리얼 통신 설정
```python
# 통신 설정
SERIAL_PORT = '/dev/serial0'  # 기본 UART
BAUD_RATE = 115200
TIMEOUT = 1.0
```

### 명령 전송 예시
```python
# 청소 명령 전송
send_command({"command": "cage_cleaning"})

# 센서 데이터 요청
send_command({"command": "get_sensor_data"})

# 긴급 정지 해제
send_command({"command": "emergency_reset"})
```

### 상태 모니터링
```python
# 실시간 상태 확인
{
  "temperature": 25.5,
  "humidity": 60.2,
  "cleaning_cycles": 3,
  "emergency_stop": false,
  "stepperRunning": false
}
```

## 🔍 문제 해결

### 일반적인 문제

#### 1. 카메라 인식 안됨
```bash
# 카메라 테스트
libcamera-hello --timeout 5000

# 권한 확인
sudo usermod -a -G video $USER
sudo reboot
```

#### 2. 시리얼 통신 안됨
```bash
# 포트 확인
ls -la /dev/serial*

# 통신 테스트
python uart_test.py

# 권한 확인
sudo usermod -a -G dialout $USER
```

#### 3. 성능 저하
```bash
# 헤드리스 모드 사용
make run-headless

# 메모리 확인
free -h

# CPU 온도 확인
vcgencmd measure_temp
```

### 성능 최적화

#### 메모리 최적화
```bash
# 스왑 메모리 설정
sudo dphys-swapfile swapoff
sudo nano /etc/dphys-swapfile
# CONF_SWAPSIZE=2048
sudo dphys-swapfile setup
sudo dphys-swapfile swapon
```

#### GPU 메모리 할당
```bash
# GPU 메모리 증가
sudo raspi-config
# 7 Advanced Options → A3 Memory Split → 128

# 또는 직접 편집
echo 'gpu_mem=128' | sudo tee -a /boot/config.txt
```

## 🧪 테스트 및 디버깅

### 시스템 테스트
```bash
# 하드웨어 테스트
python uart_test.py

# 카메라 테스트
python test_imports.py

# 전체 시스템 테스트
make run-test
```

### 디버그 모드
```bash
# 디버그 로그 활성화
uv run clean-system --debug

# 로그 파일 확인
tail -f detection_log.txt
```

### 성능 모니터링
```bash
# 시스템 리소스 모니터링
htop

# GPU 메모리 확인
vcgencmd get_mem arm && vcgencmd get_mem gpu

# 온도 모니터링
watch -n 1 vcgencmd measure_temp
```

## 📁 관련 문서

- **Arduino 펌웨어**: [`../Arduino/README.md`](../Arduino/README.md)
- **하드웨어 연결**: [`../Arduino/HARDWARE_CONNECTION.md`](../Arduino/HARDWARE_CONNECTION.md)
- **하드웨어 전체**: [`../README.md`](../README.md)
- **전체 프로젝트**: [`../../../README.md`](../../../README.md)

---

**🎯 라즈베리파이 목표**: 안정적이고 정확한 AI 새똥 탐지 시스템 구현  
**🛠️ 개발 환경**: Raspberry Pi OS, Python 3.9+, uv 패키지 관리자

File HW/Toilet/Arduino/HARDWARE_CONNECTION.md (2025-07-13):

# 🔌 새장 화장실 자동 청소 시스템 - 하드웨어 연결 가이드

**라즈베리파이 4 + Arduino Uno 기반 MG996R 360도 서보모터 청소 시스템**

AI 새똥 탐지 및 자동 청소 시스템의 완전한 하드웨어 연결 및 설치 가이드입니다.

> 📖 **전체 프로젝트 개요**: [`../../../README.md`](../../../README.md)  
> 📖 **하드웨어 전체 가이드**: [`../README.md`](../README.md)  
> 📖 **Arduino 펌웨어 가이드**: [`README.md`](README.md)  
> 📖 **라즈베리파이 시스템**: [`../Raspberrypi/README.md`](../Raspberrypi/README.md)

## 🎯 실제 구현된 시스템 구성

### 🔗 전체 연결 구조 (main.cpp 기준)
```
┌─────────────────────────────────────────────────────────────────┐
│                    라즈베리파이 4 (메인 시스템)                    │
│ ┌─────────────────┐  ┌─────────────────┐  ┌─────────────────┐ │
│ │   PI 카메라     │  │   YOLO 커스텀   │  │   시스템 제어   │ │
│ │   (CSI 포트)    │  │   모델 탐지     │  │   (Python)      │ │
│ └─────────────────┘  └─────────────────┘  └─────────────────┘ │
│                                                 │               │
│                                        GPIO 14/15 (UART)       │
└─────────────────────────────────────────────────┼───────────────┘
                                                  │
                                            시리얼 통신
                                            (115200 baud)
                                                  │
┌─────────────────────────────────────────────────┼───────────────┐
│                   Arduino Uno (하드웨어 제어)   │               │
│ ┌─────────────────┐  ┌─────────────────┐  ┌─────────────────┐ │
│ │   DHT11 센서    │  │   MG996R 360도  │  │   긴급 정지     │ │
│ │   (D2)          │  │   서보모터 (D9) │  │   버튼 (D3)     │ │
│ │   온습도 측정   │  │   청소 장치     │  │   안전 시스템   │ │
│ └─────────────────┘  └─────────────────┘  └─────────────────┘ │
│                                                               │
│ ┌─────────────────┐  ┌─────────────────┐  ┌─────────────────┐ │
│ │   쓰레기통      │  │   상태 LED      │  │   알림 부저     │ │
│ │   비우기 (D4)   │  │   (D13)         │  │   (D11)         │ │
│ └─────────────────┘  └─────────────────┘  └─────────────────┘ │
└─────────────────────────────────────────────────────────────────┘
```

## 📋 실제 사용된 하드웨어 (main.cpp 기준)

### 🖥️ 메인 시스템
| 부품 | 모델 | 수량 | 용도 |
|---|---|---|---|
| 라즈베리파이 4 | 4GB 이상 권장 | 1 | AI 탐지 및 시스템 제어 |
| MicroSD 카드 | 64GB 이상, Class 10 | 1 | 운영체제 및 데이터 저장 |
| 전원 어댑터 | 5V 3A USB-C | 1 | 라즈베리파이 전원 공급 |
| PI 카메라 모듈 | v2/v3 (1080p) | 1 | 새똥 탐지 영상 입력 |
| 카메라 케이블 | 15핀 CSI | 1 | 카메라 ↔ 라즈베리파이 연결 |

### 🔧 하드웨어 제어 (실제 구현)
| 부품 | 모델 | 수량 | 용도 |
|---|---|---|---|
| Arduino Uno | R3 | 1 | 하드웨어 제어 보드 |
| DHT11 센서 | 온습도 센서 | 1 | 환경 모니터링 |
| **MG996R 서보모터** | **360도 연속회전 서보** | **1** | **청소 장치 (메인)** |

### 🚨 안전 및 상태 표시 (실제 구현)
| 부품 | 모델 | 수량 | 용도 |
|---|---|---|---|
| 긴급 정지 버튼 | 택트 스위치 | 1 | 긴급 정지 (D3) |
| 쓰레기통 비우기 버튼 | 택트 스위치 | 1 | 쓰레기통 관리 (D4) |
| LED | 5mm 빨간색 | 1 | 시스템 상태 표시 (D13) |
| 부저 | 액티브 부저 | 1 | 알림음 (D11) |

### 🔌 연결 부품
| 부품 | 수량 | 용도 |
|---|---|---|
| 점퍼 와이어 (M-M) | 15개 | Arduino 내부 연결 |
| 점퍼 와이어 (M-F) | 5개 | 센서 연결 |
| 브레드보드 | 1개 | 프로토타이핑 |
| 저항 10kΩ | 3개 | 풀업 저항 (DHT11, 버튼 2개) |
| 저항 220Ω | 1개 | LED 전류 제한 |

## 🔌 실제 핀 배치 (main.cpp 정확한 구현)

### 📍 Arduino Uno 핀 사용 현황
| 핀 번호 | 부품 | 기능 | 코드 상의 정의 |
|---|---|---|---|
| **D2** | DHT11 센서 | 온습도 데이터 읽기 | `#define DHTPIN 2` |
| **D3** | 긴급 정지 버튼 | 인터럽트 (풀업 저항) | `#define EMERGENCY_STOP_PIN 3` |
| **D4** | 쓰레기통 비우기 버튼 | 디지털 입력 (풀업 저항) | `#define TRASH_EMPTY_BUTTON_PIN 4` |
| **D9** | **MG996R 360도 서보모터** | **PWM 신호 (청소 장치)** | `#define CLEANING_SERVO_PIN 9` |
| **D11** | 알림 부저 | PWM 신호 (상태 알림음) | `#define BUZZER_PIN 11` |
| **D13** | 상태 LED | 디지털 출력 (시스템 상태) | `#define STATUS_LED_PIN 13` |

### 📊 전원 연결 정리
| 전원 | 연결 부품 |
|---|---|
| **5V** | DHT11 VCC, MG996R VCC, 풀업 저항 |
| **GND** | DHT11 GND, MG996R GND, 버튼 2개, LED, 부저 |

## 🔄 MG996R 360도 서보모터 청소 시스템 (실제 구현)

### 🎯 청소 프로세스 (main.cpp `performCageCleaning()`)
```
1단계: 앞으로 3초 회전
├── PWM 신호: 1700us
├── 지속 시간: 3초
└── 코드: controlServo(1)

2단계: 뒤로 3초 회전  
├── PWM 신호: 1300us
├── 지속 시간: 3초
└── 코드: controlServo(-1)

3단계: 정지
├── PWM 신호: 1500us
├── 청소 카운터 증가
└── 코드: stopServo()
```

### 🔧 PWM 신호 제어 (main.cpp 기준)
```cpp
// 서보모터 제어 상수 (ServoConfig namespace)
const int SERVO_STOP = 1500;           // 정지 위치 (1500us)
const int SERVO_FORWARD = 1700;        // 앞으로 회전 (1700us)
const int SERVO_BACKWARD = 1300;       // 뒤로 회전 (1300us)
const unsigned long CLEANING_DURATION = 3000;  // 청소 시간 (3초)
```

## 🗑️ 쓰레기통 관리 시스템 (실제 구현)

### 📊 10회 청소 후 관리 (main.cpp 기준)
```cpp
// 10번 청소 후 쓰레기통 가득 참 상태로 설정
if (systemStatus.cleaning_cycles >= 10) {
    systemStatus.trash_full = true;
    Serial.println(F("{\"alert\":\"TRASH_FULL_AFTER_10_CLEANINGS\"}"));
}
```

### 🔄 쓰레기통 비우기 프로세스
1. **10번 청소 완료** → 자동으로 `trash_full = true`
2. **쓰레기통 비우기 버튼 (D4) 누름** → `handleTrashEmptyButton()`
3. **청소 카운터 리셋** → `cleaning_cycles = 0`
4. **시스템 재시작** → 정상 청소 재개

## 🔌 상세 연결 가이드

### 1️⃣ 라즈베리파이 4 설정

#### 📦 라즈베리파이 준비
```bash
# 1. Raspberry Pi OS 설치 (Raspberry Pi Imager 사용)
# 2. SSH 및 카메라 활성화
sudo raspi-config
# 3 Interface Options → I1 Camera → Yes
# 3 Interface Options → I2 SSH → Yes

# 3. 시스템 업데이트
sudo apt update && sudo apt upgrade -y

# 4. 필수 패키지 설치
sudo apt install -y python3-picamera2 libcamera-apps python3-dev
```

#### 📷 PI 카메라 모듈 연결
```
PI 카메라 모듈 → 라즈베리파이 CSI 포트 (Camera Serial Interface)
```

**연결 방법:**
1. 라즈베리파이 전원 끄기
2. CSI 포트의 플라스틱 클립 들어올리기
3. 카메라 플렉스 케이블의 **금속 접점이 아래를 향하도록** 삽입
4. 플라스틱 클립 다시 눌러서 고정
5. 전원 켜기

**카메라 테스트:**
```bash
# 카메라 연결 확인
libcamera-hello --timeout 5000

# 사진 촬영 테스트
libcamera-still -o test.jpg
```

### 2️⃣ Arduino Uno 연결

#### 🔗 라즈베리파이 ↔ Arduino 연결
```
라즈베리파이 → Arduino
GPIO 14 (TXD) → RX (D0)
GPIO 15 (RXD) → TX (D1)
GND → GND (공통 접지)
```

**시리얼 통신 설정:**
```bash
# 시리얼 포트 확인
ls -la /dev/serial*

# 권한 설정
sudo usermod -a -G dialout $USER

# 부팅 시 시리얼 콘솔 비활성화
sudo raspi-config
# 3 Interface Options → I6 Serial Port → No (로그인 shell) → Yes (시리얼 포트 하드웨어)
```

### 3️⃣ DHT11 온습도 센서 연결 (D2)

#### 📊 DHT11 센서 → Arduino 연결
```
DHT11 센서     Arduino Uno
┌─────────┐   ┌─────────────┐
│   VCC   │──→│     5V      │
│   DATA  │──→│Digital Pin 2│ (10kΩ 풀업 저항 연결)
│   GND   │──→│     GND     │
└─────────┘   └─────────────┘
```

**풀업 저항 연결:**
```
Digital Pin 2 ──┬── DHT11 DATA
                │
               10kΩ
                │
               5V
```

### 4️⃣ MG996R 360도 서보모터 연결 (D9) - 메인 청소 장치

#### 🔄 MG996R 서보모터 → Arduino 연결
```
MG996R 서보모터  Arduino Uno
┌─────────────┐  ┌─────────────┐
│   VCC (빨강) │←─│     5V      │
│   GND (갈색) │←─│     GND     │
│ Signal (주황)│←─│Digital Pin 9│
└─────────────┘  └─────────────┘
```

**MG996R 360도 서보모터 사양:**
- **토크**: 13kg·cm (4.8V), 15kg·cm (6.0V)
- **속도**: 0.19sec/60° (4.8V), 0.15sec/60° (6.0V)
- **전원**: 4.8V-7.2V
- **제어**: 1000-2000μs PWM (20ms 주기)
- **회전**: 연속 회전 가능

**실제 구현된 PWM 제어 (main.cpp):**
- **1700us**: 앞으로 회전 (3초간)
- **1300us**: 뒤로 회전 (3초간)
- **1500us**: 정지

### 5️⃣ 안전 및 상태 표시 장치 연결

#### 🚨 긴급 정지 버튼 연결 (D3)
```
긴급 정지 버튼   Arduino Uno
┌─────────────┐ ┌─────────────┐
│   한쪽 핀   │─┬─│Digital Pin 3│ (인터럽트 핀)
│            │ │ │            │
│   다른 핀   │─┼─│     GND     │
│            │ │ │            │
└─────────────┘ │ └─────────────┘
                │
               10kΩ (풀업 저항)
                │
               5V
```

#### 🗑️ 쓰레기통 비우기 버튼 연결 (D4)
```
쓰레기통 버튼    Arduino Uno
┌─────────────┐ ┌─────────────┐
│   한쪽 핀   │─┬─│Digital Pin 4│
│            │ │ │            │
│   다른 핀   │─┼─│     GND     │
│            │ │ │            │
└─────────────┘ │ └─────────────┘
                │
               10kΩ (풀업 저항)
                │
               5V
```

#### 💡 상태 LED 연결 (D13)
```
상태 LED        Arduino Uno
┌─────────────┐ ┌─────────────┐
│   애노드(+) │←┤220Ω 저항├──│Digital Pin 13│
│   캐소드(-) │←────────────│     GND     │
└─────────────┘ └─────────────┘
```

#### 🔊 알림 부저 연결 (D11)
```
알림 부저       Arduino Uno
┌─────────────┐ ┌─────────────┐
│   양극(+)   │←──│Digital Pin 11│
│   음극(-)   │←──│     GND     │
└─────────────┘ └─────────────┘
```

## 🔬 연결 테스트 및 검증

### 1️⃣ 하드웨어 테스트 순서

#### 📋 라즈베리파이 테스트
```bash
# 1. 카메라 연결 확인
libcamera-hello --timeout 3000

# 2. 시리얼 통신 확인
ls -la /dev/serial*

# 3. GPIO 핀 상태 확인
gpio readall
```

#### 🔌 Arduino 테스트
```bash
# 1. Arduino 연결 확인
ls /dev/ttyUSB* /dev/ttyACM*

# 2. 펌웨어 업로드
cd /home/parrot1/gongdol/Inventon_Gongdol/HW/Toilet/Arduino
platformio run --target upload

# 3. 시리얼 모니터
platformio device monitor
```

### 2️⃣ 개별 부품 테스트 (JSON 명령어)

#### 🌡️ DHT11 센서 테스트
```json
예상 시리얼 출력:
{
  "temperature": 25.5,
  "humidity": 60.2,
  "servoRunning": false,
  "servoDirection": 0,
  "trashFull": false,
  "trashEmptyButtonPressed": false,
  "timestamp": 1234567890
}
```

#### 🔄 MG996R 서보모터 테스트
```bash
# 라즈베리파이에서 테스트 명령 전송
cd /home/parrot1/gongdol/Inventon_Gongdol/HW/Toilet/Raspberrypi
python uart_test.py

# 또는 직접 명령 전송
echo '{"command": "cage_cleaning"}' > /dev/serial0

# 개별 방향 테스트
echo '{"command": "control_servo", "direction": 1}' > /dev/serial0   # 앞으로
echo '{"command": "control_servo", "direction": -1}' > /dev/serial0  # 뒤로
echo '{"command": "servo_stop"}' > /dev/serial0                      # 정지
```

#### 🗑️ 쓰레기통 관리 테스트
```bash
# 청소 횟수 초기화
echo '{"command": "reset_cleaning_cycles"}' > /dev/serial0

# 쓰레기통 비우기 버튼 테스트
echo '{"command": "trash_empty_button"}' > /dev/serial0
```

## 🎯 실제 시스템 동작 (main.cpp 기준)

### 🔄 청소 프로세스 흐름
```
새똥 탐지 (라즈베리파이)
        ↓
{"command": "cage_cleaning"} 전송
        ↓
1단계: MG996R 앞으로 3초 (1700us PWM)
        ↓
2단계: MG996R 뒤로 3초 (1300us PWM)  
        ↓
3단계: 정지 (1500us PWM)
        ↓
청소 카운터 증가 (cleaning_cycles++)
        ↓
10회 달성 시 trash_full = true
        ↓
쓰레기통 비우기 버튼 대기
```

### 📊 시스템 상태 모니터링
```json
시스템 상태 JSON 응답:
{
  "status": "ready",
  "emergency_stop": false,
  "cleaning_cycles": 5,
  "cleaning_servo_active": false,
  "last_cleaning": 1234567890,
  "trash_full": false,
  "free_memory": 1500
}
```

## ⚠️ 주의사항 및 안전 가이드

### 🔒 전기 안전
- ⚡ **전원 차단 후 연결 작업 필수**
- 🔌 **극성 확인**: VCC(+), GND(-) 올바른 연결
- 🛡️ **단락 방지**: 와이어 절연 상태 확인
- 🔋 **전류 제한**: LED는 반드시 저항과 함께 연결
- ⚠️ **MG996R 전원**: 충분한 전류 공급 (최소 1A 권장)

### 🔧 기계적 안전
- 🔩 **서보모터 고정**: MG996R 진동으로 인한 이탈 방지
- 📷 **카메라 고정**: 흔들림으로 인한 탐지 오류 방지
- 🔌 **케이블 정리**: 동물이 케이블에 걸리지 않도록 정리
- 🛠️ **정기 점검**: 나사 풀림, 케이블 마모 등 확인

### 💡 성능 최적화
- 🌡️ **방열판 부착**: 라즈베리파이 CPU 과열 방지
- ⚡ **안정적 전원**: 5V 3A 이상 고품질 전원 어댑터 사용
- 🔌 **공통 접지**: 모든 GND를 한 점에서 연결하여 노이즈 감소
- 📶 **케이블 길이**: 신호 손실 최소화를 위해 최단 거리 연결

## 🔍 문제 해결 가이드

### 📷 PI 카메라 문제

#### 카메라 인식 안됨
```bash
# 카메라 상태 확인
vcgencmd get_camera

# 카메라 인터페이스 활성화
sudo raspi-config
# 3 Interface Options → I1 Camera → Yes

# 권한 확인
sudo usermod -a -G video $USER
sudo reboot
```

### 🔌 Arduino 통신 문제

#### 시리얼 포트 인식 안됨
```bash
# 포트 확인
ls -la /dev/serial* /dev/ttyUSB* /dev/ttyACM*

# 권한 설정
sudo usermod -a -G dialout $USER
sudo chmod 666 /dev/serial0

# 통신 테스트
echo '{"command": "get_sensor_data"}' > /dev/serial0
```

### 🔄 MG996R 서보모터 문제

#### 서보모터 동작 안됨
- **전원 공급 확인**: 5V 충분한 전류 (1A 이상)
- **신호선 연결**: Digital Pin 9 연결 확인
- **PWM 신호 확인**: 1000-2000μs 범위 신호

#### 서보모터 떨림 현상
```cpp
// 코드에서 확인할 설정
const int SERVO_CYCLE_TIME = 20;       // PWM 주기 (20ms)
const unsigned long CLEANING_DURATION = 3000;  // 청소 시간 (3초)
```

### 🌡️ DHT11 센서 문제

#### 센서 데이터 읽기 실패
- **전원 공급 확인**: 5V 안정적 공급
- **데이터 핀 연결**: Digital Pin 2 연결 확인
- **풀업 저항**: 10kΩ 저항 연결 확인

### 🚨 버튼 문제

#### 긴급 정지 버튼 인식 안됨
```cpp
// 풀업 저항 설정 확인 (코드)
pinMode(EMERGENCY_STOP_PIN, INPUT_PULLUP);

// 버튼 상태 확인
if (digitalRead(EMERGENCY_STOP_PIN) == LOW) {
    // 긴급 정지 동작
}
```

## 🎉 최종 시스템 통합 테스트

### ✅ 단계별 테스트 체크리스트

#### 1단계: 하드웨어 연결 점검
- [ ] 모든 전원 연결 확인 (5V, GND)
- [ ] 시리얼 통신 연결 확인 (GPIO 14/15)
- [ ] DHT11 센서 연결 확인 (D2)
- [ ] MG996R 서보모터 연결 확인 (D9)
- [ ] 안전 버튼 연결 확인 (D3, D4)
- [ ] 상태 표시 장치 연결 확인 (D11, D13)

#### 2단계: 펌웨어 업로드
```bash
cd /home/parrot1/gongdol/Inventon_Gongdol/HW/Toilet/Arduino
platformio run --target upload
```

#### 3단계: 시스템 실행
```bash
cd /home/parrot1/gongdol/Inventon_Gongdol/HW/Toilet/Raspberrypi
uv run clean-system
```

#### 4단계: 기능 검증
- [ ] 카메라 영상 정상 출력
- [ ] AI 새똥 탐지 동작
- [ ] 시리얼 통신 데이터 수신
- [ ] MG996R 앞으로 회전 (1700us)
- [ ] MG996R 뒤로 회전 (1300us)
- [ ] MG996R 정지 (1500us)
- [ ] 긴급 정지 버튼 동작
- [ ] 쓰레기통 비우기 버튼 동작
- [ ] 10회 청소 후 쓰레기통 가득 참 알림
- [ ] 상태 LED 및 부저 동작

## 📁 관련 문서 및 리소스

### 📖 프로젝트 문서
- **전체 프로젝트 개요**: [`../../../README.md`](../../../README.md)
- **하드웨어 전체 가이드**: [`../README.md`](../README.md)
- **Arduino 펌웨어**: [`README.md`](README.md)
- **라즈베리파이 시스템**: [`../Raspberrypi/README.md`](../Raspberrypi/README.md)

### 🔧 기술 참고 자료
- **Arduino 공식 문서**: https://www.arduino.cc/reference/en/
- **라즈베리파이 공식 문서**: https://www.raspberrypi.org/documentation/
- **DHT11 센서 라이브러리**: https://github.com/adafruit/DHT-sensor-library
- **MG996R 서보모터 가이드**: https://components101.com/servo-motor-basics-pinout-datasheet

---

**🎯 하드웨어 연결 목표**: MG996R 360도 서보모터 기반 안정적 청소 시스템 구축  
**🛠️ 지원 환경**: Arduino IDE 1.8.19+, PlatformIO Core 6.0+, Raspberry Pi OS  
**📌 펌웨어 버전**: v1.3.1 (Bird Cage Toilet Cleaning System)

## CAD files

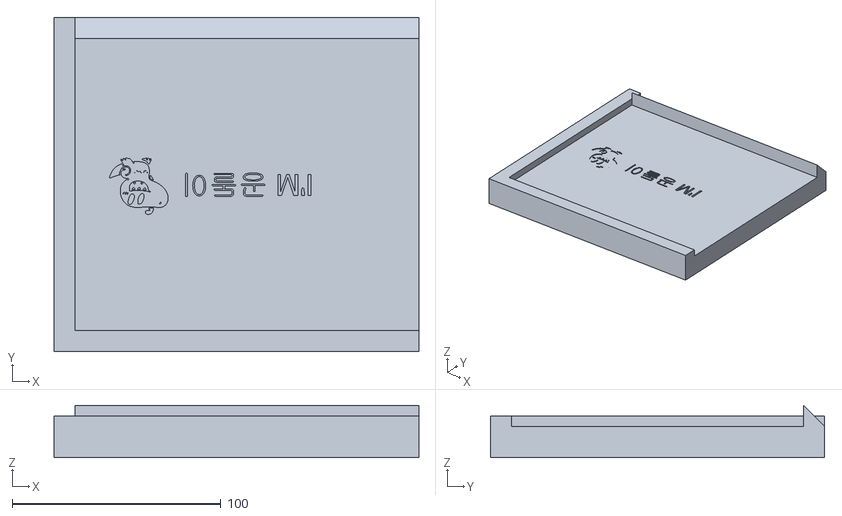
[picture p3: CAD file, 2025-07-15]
Design/body/middle plate_teamname_07151320.stl
175.0 x 160.0 x 25.0

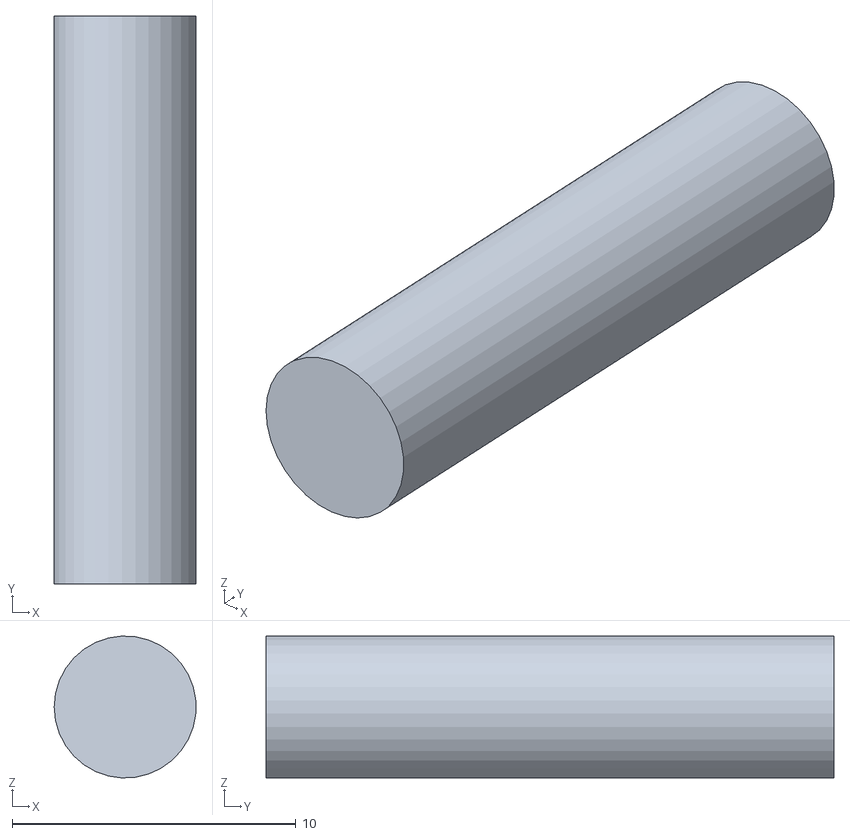
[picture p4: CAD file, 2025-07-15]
Design/supplier/feed supplier/storage_hatch connector07151610.stl
4.99 x 20.0 x 4.99

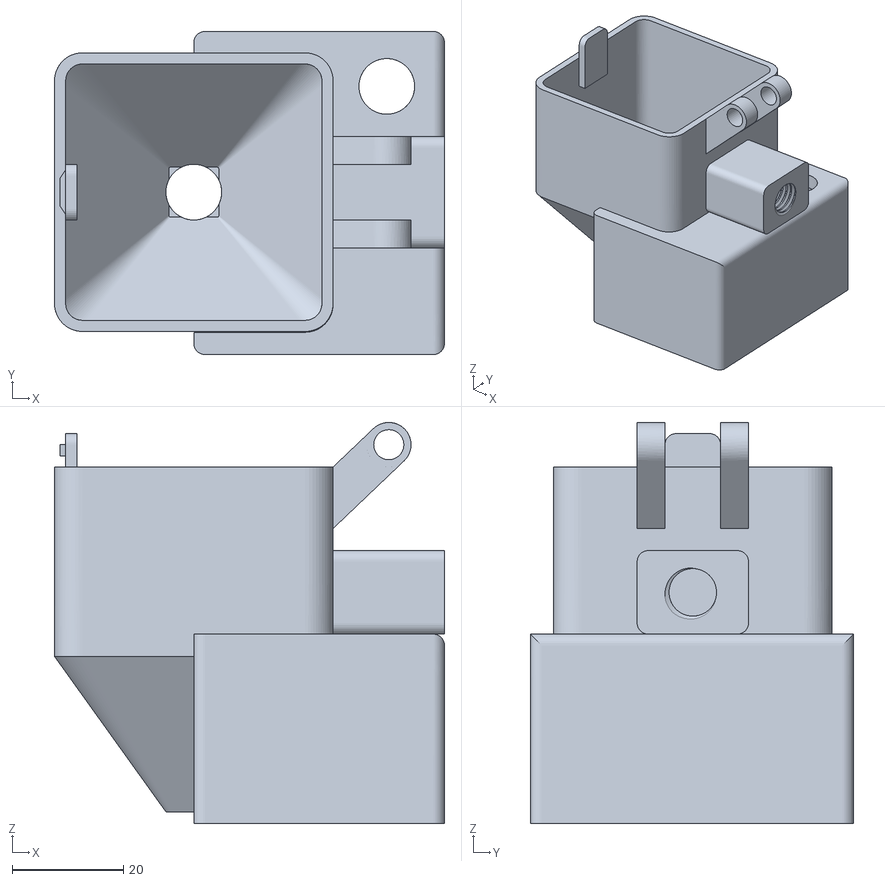
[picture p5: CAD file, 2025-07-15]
Design/supplier/feed supplier/feed storage 07151610.stl
70.0 x 58.0 x 72.0

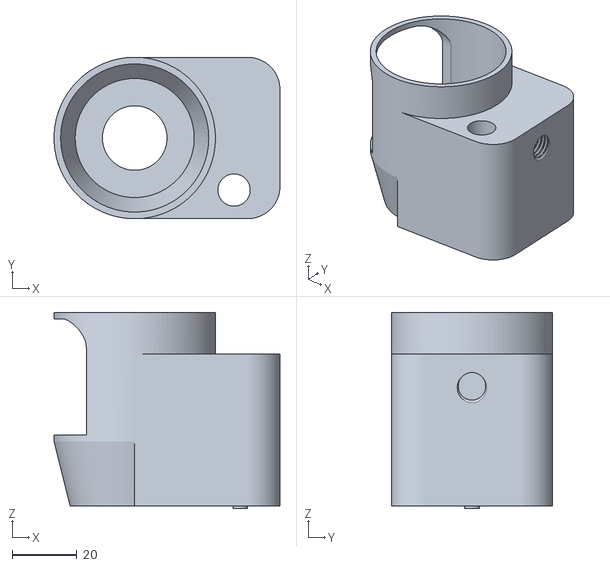
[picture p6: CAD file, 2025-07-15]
Design/supplier/feed supplier/feed bowl 07151610.stl
70.0 x 50.0 x 60.8

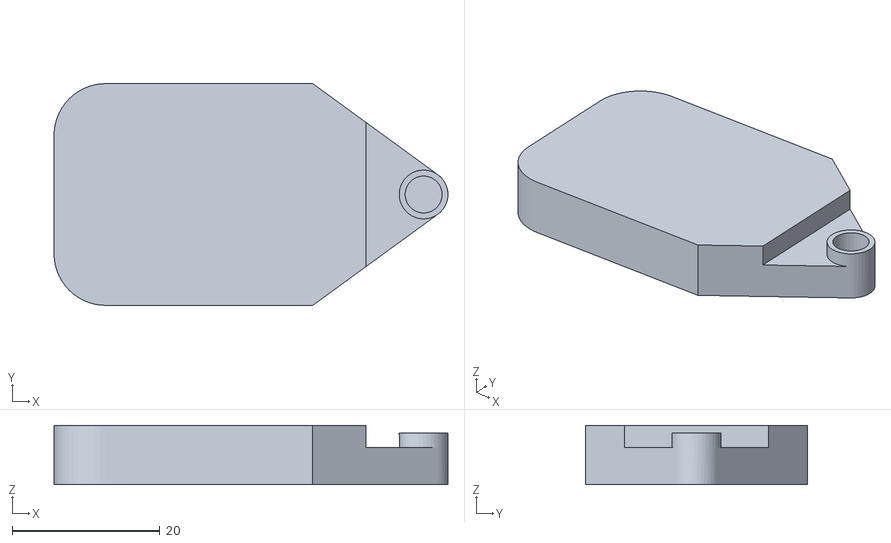
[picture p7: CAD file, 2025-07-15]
Design/supplier/feed supplier/feed bowl_servo connector 07151610.stl
53.3 x 30.0 x 8.00

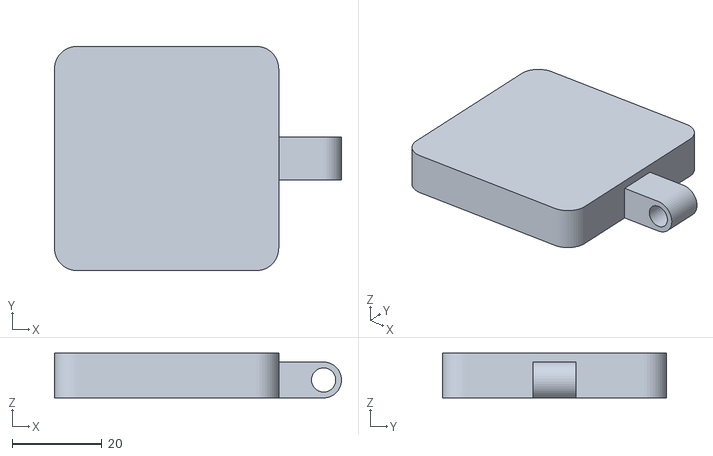
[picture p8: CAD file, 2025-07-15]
Design/supplier/feed supplier/feed storage hatch 07151610.stl
64.0 x 50.0 x 10.0

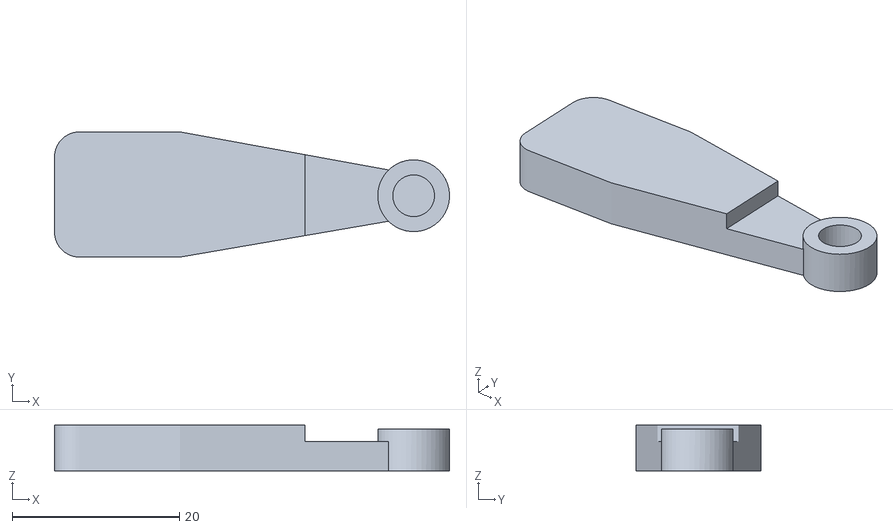
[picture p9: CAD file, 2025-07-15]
Design/supplier/feed supplier/storage servo connector071610.stl
47.3 x 15.0 x 5.50

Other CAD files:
Design/body/middle plate 07151235.stl

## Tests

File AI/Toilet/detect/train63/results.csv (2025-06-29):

epoch | time | train/box_loss | train/cls_loss | train/dfl_loss | metrics/precision(B) | metrics/recall(B) | metrics/mAP50(B) | metrics/mAP50-95(B) | val/box_loss | val/cls_loss | val/dfl_loss | lr/pg0 | lr/pg1 | lr/pg2
1 | 7.45234 | 2.80534 | 3.13684 | 2.12825 | 0 | 0 | 0 | 0 | 3.98773 | 3.53782 | 6.86378 | 0.000648649 | 0.000648649 | 0.000648649
2 | 14.2587 | 2.54643 | 2.72988 | 1.85968 | 0 | 0 | 0 | 0 | 1.98308 | 23.0156 | 3.21686 | 0.00130229 | 0.00130229 | 0.00130229
3 | 20.5962 | 2.35696 | 2.46588 | 1.70243 | 0.87959 | 1 | 0.995 | 0.10293 | 3.17454 | 8.50331 | 4.63779 | 0.00194274 | 0.00194274 | 0.00194274
4 | 27.1761 | 2.27131 | 2.35385 | 1.66593 | 0.95104 | 1 | 0.995 | 0.6965 | 1.39281 | 4.25352 | 1.37041 | 0.0019406 | 0.0019406 | 0.0019406
5 | 30.4742 | 2.2094 | 2.28086 | 1.61447 | 0.147 | 1 | 0.24875 | 0.10528 | 1.52245 | 4.25138 | 1.20221 | 0.0019208 | 0.0019208 | 0.0019208
6 | 36.8881 | 2.11066 | 2.13195 | 1.55366 | 0.00333 | 1 | 0.06219 | 0.02488 | 3.10491 | 4.06479 | 2.32865 | 0.001901 | 0.001901 | 0.001901
7 | 43.7209 | 2.10149 | 2.11225 | 1.54134 | 0.80605 | 1 | 0.995 | 0.56383 | 1.09464 | 2.28574 | 1.07497 | 0.0018812 | 0.0018812 | 0.0018812
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

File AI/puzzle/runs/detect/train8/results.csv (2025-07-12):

epoch | time | train/box_loss | train/cls_loss | train/dfl_loss | metrics/precision(B) | metrics/recall(B) | metrics/mAP50(B) | metrics/mAP50-95(B) | val/box_loss | val/cls_loss | val/dfl_loss | lr/pg0 | lr/pg1 | lr/pg2
1 | 5.40599 | 0.92255 | 2.93014 | 1.16887 | 0.0031 | 1 | 0.61718 | 0.52723 | 0.5059 | 2.85798 | 0.95994 | 0.00021671 | 0.00021671 | 0.00021671
2 | 8.66792 | 0.77447 | 1.83358 | 1.13173 | 0.00308 | 1 | 0.71411 | 0.6101 | 0.50547 | 2.66169 | 0.9496 | 0.000445634 | 0.000445634 | 0.000445634
3 | 11.2757 | 0.80392 | 1.59943 | 1.15813 | 0.00308 | 1 | 0.62991 | 0.51243 | 0.66583 | 2.57975 | 1.05039 | 0.000669937 | 0.000669937 | 0.000669937
4 | 13.8559 | 0.82202 | 1.42553 | 1.1298 | 0.90046 | 0.07893 | 0.51659 | 0.39052 | 1.07509 | 2.60162 | 1.33498 | 0.00088962 | 0.00088962 | 0.00088962
5 | 16.1202 | 0.84076 | 1.34898 | 1.10168 | 0.93413 | 0.38773 | 0.62081 | 0.41921 | 1.02847 | 1.99347 | 1.34441 | 0.00110468 | 0.00110468 | 0.00110468
6 | 18.2465 | 0.80275 | 1.22673 | 1.06971 | 0.75128 | 0.76668 | 0.84866 | 0.63137 | 0.76815 | 1.71231 | 1.1546 | 0.00131512 | 0.00131512 | 0.00131512
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

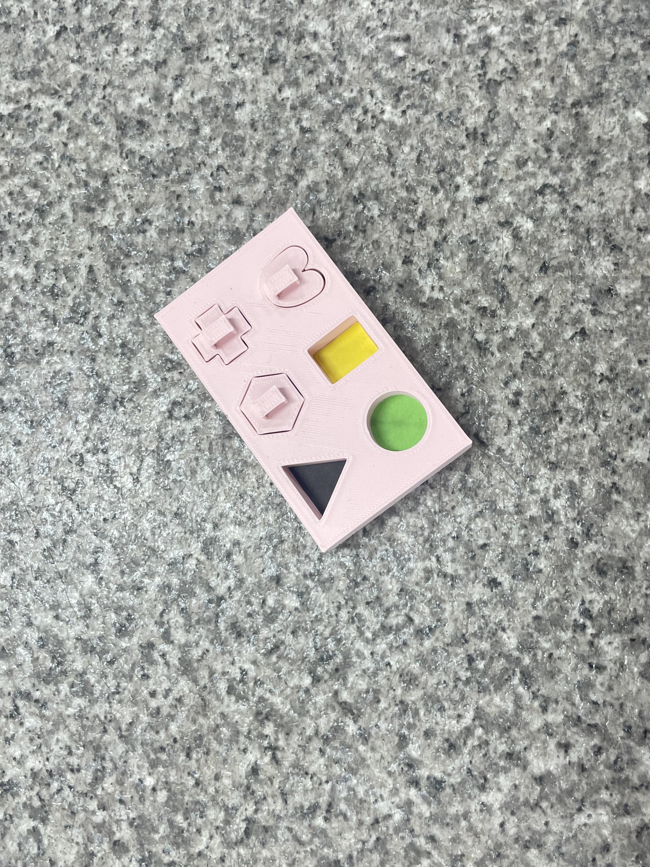
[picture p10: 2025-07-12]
HW/puzzle/AI/my-project/Parrot Puzzle.v2i.yolov11/test/images/KakaoTalk_20250710_175857867_18_jpg.rf.7ea17fb763f0be989c8c2a4cc3170363.jpg

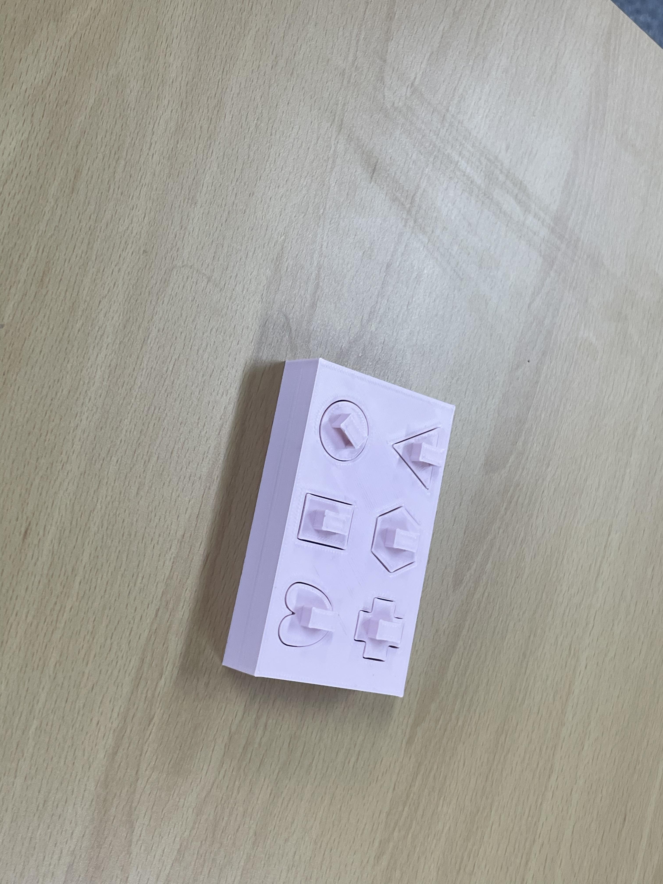
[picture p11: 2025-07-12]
HW/puzzle/AI/my-project/Parrot Puzzle.v2i.yolov11/test/images/KakaoTalk_20250710_180446371_25_jpg.rf.a1866dec0e4dc2d1a62cc9ef36b43936.jpg

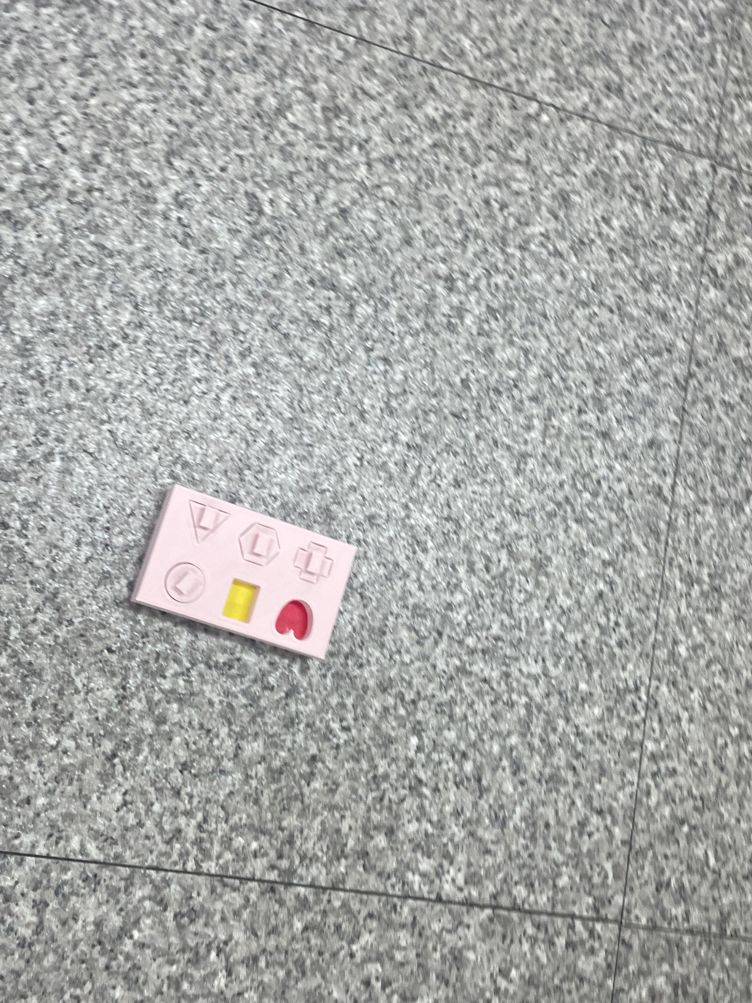
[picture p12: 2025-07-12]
AI/puzzle/my-project/Parrot Puzzle.v2i.yolov11/test/images/KakaoTalk_20250710_180337943_11_jpg.rf.978ba134b3f2c26e8a326a5ae8dc145a.jpg

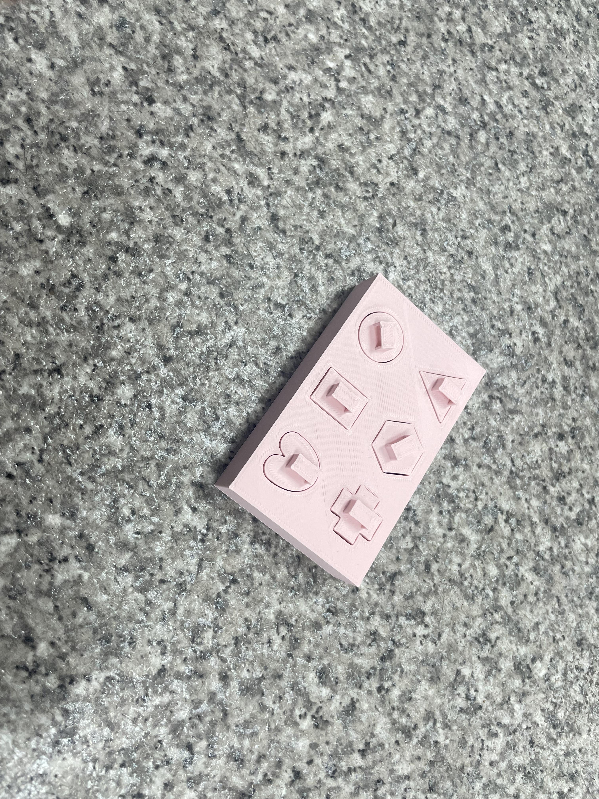
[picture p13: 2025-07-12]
AI/puzzle/my-project/Parrot Puzzle.v2i.yolov11/test/images/KakaoTalk_20250710_180438748_29_jpg.rf.235d435d066ab15adbe9d2848d056b04.jpg

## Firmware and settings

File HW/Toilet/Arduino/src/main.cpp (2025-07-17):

#include <Arduino.h>
#include <DHT11.h> // 사용하시는 DHT11 라이브러리
#include <Servo.h>

// ================================================================================
// 핀 번호 정의 (기존 설정 유지)
// ================================================================================
#define DHT_PIN 2
#define SERVO_PIN 6
#define LED_PIN 7
#define BUZZER_PIN 5
#define EMERGENCY_STOP_PIN 3
#define TRASH_EMPTY_BUTTON_PIN 4

// ================================================================================
// 상수 정의 (기존 설정 유지)
// ================================================================================
namespace CleaningConfig {
  const unsigned long DURATION = 3000; // 청소 동작 시간 (3초)
}

// ================================================================================
// 전역 객체 및 변수
// ================================================================================
DHT11 dht11(DHT_PIN); // 라이브러리에 맞게 객체 생성
Servo cleaningServo;

// 시스템 상태 변수
bool isEmergencyStopped = false;
byte cleaningCycleCount = 0;

// ================================================================================
// 함수 프로토타입
// ================================================================================
void performCleaningSequence();
void sendSensorData();
void playBuzzer(int frequency, int duration);
void handleEmergencyStop();

// ================================================================================
// SETUP: 시스템 초기화
// ================================================================================
void setup() {
  // 시리얼 통신 시작 (안정적인 9600 보드레이트 사용)
  Serial.begin(115200);
  
  // 핀 모드 설정
  pinMode(LED_PIN, OUTPUT);
  pinMode(BUZZER_PIN, OUTPUT);
  pinMode(EMERGENCY_STOP_PIN, INPUT_PULLUP);
  pinMode(TRASH_EMPTY_BUTTON_PIN, INPUT_PULLUP);
  
  // 서보모터 연결 및 초기화
  cleaningServo.attach(SERVO_PIN);
  cleaningServo.write(90); // 0도(원점)에서 시작
  
  // 긴급 정지 인터럽트 설정
  attachInterrupt(digitalPinToInterrupt(EMERGENCY_STOP_PIN), handleEmergencyStop, FALLING);
  
  // 시작 알림
  digitalWrite(LED_PIN, HIGH);
  tone(BUZZER_PIN, 1000, 200);
  delay(500);
  digitalWrite(LED_PIN, LOW);
  
  Serial.println("Arduino Ready. Simple Command Mode.");
}

// ================================================================================
// LOOP: 메인 루프
// ================================================================================
void loop() {
  // 긴급 정지 상태에서는 아무것도 하지 않음
  if (isEmergencyStopped) {
    // 2초 이상 길게 누르면 긴급 정지 해제
    if (digitalRead(EMERGENCY_STOP_PIN) == LOW) {
      delay(2000);
      if (digitalRead(EMERGENCY_STOP_PIN) == LOW) {
        isEmergencyStopped = false;
        digitalWrite(LED_PIN, LOW);
        Serial.println("OK: Emergency stop released.");
      }
    }
    return;
  }
  
  // 쓰레기통 비우기 버튼 감지
  if (digitalRead(TRASH_EMPTY_BUTTON_PIN) == LOW) {
      delay(100); // 디바운싱
      if (digitalRead(TRASH_EMPTY_BUTTON_PIN) == LOW) {
        cleaningCycleCount = 0;
        Serial.println("OK: Cleaning cycles reset.");
        playBuzzer(1500, 100);
        delay(1000); // 중복 리셋 방지
      }
  }

  // 라즈베리파이로부터 명령 수신 처리
  if (Serial.available() > 0) {
    char command = Serial.read();

    switch (command) {
      case '1': // LED 켜기
        digitalWrite(LED_PIN, HIGH);
        Serial.println("OK: LED ON");
        break;
        
      case '2': // LED 끄기
        digitalWrite(LED_PIN, LOW);
        Serial.println("OK: LED OFF");
        break;
        
      case '3': // 버저 울림
        playBuzzer(1200, 100);
        Serial.println("OK: BUZZER");
        break;
        
      case '4': // 전체 청소 시퀀스 실행
        performCleaningSequence();
        break;
        
      case '6': // 온습도 데이터 전송 요청
        sendSensorData();
        break;
    }
  }
}

// ================================================================================
// 핵심 기능 함수
// ================================================================================

/**
 * @brief 전체 청소 시퀀스를 수행합니다. (LED, 부저, 서보모터)
 */
void performCleaningSequence() {
  Serial.println("INFO: Cleaning sequence started.");
  digitalWrite(LED_PIN, HIGH);
  playBuzzer(1000, 150);

  // 1. 앞으로 이동
  cleaningServo.write(0);
  delay(CleaningConfig::DURATION);

  // 2. 뒤로 복귀
  cleaningServo.write(180);
  delay(CleaningConfig::DURATION);
  
  digitalWrite(LED_PIN, LOW);
  playBuzzer(1500, 150);
  cleaningServo.write(90);
  cleaningCycleCount++;
  Serial.print("OK: Cleaning complete. Count: ");
  Serial.println(cleaningCycleCount);
}

/**
 * @brief DHT11 센서 값을 읽어 시리얼로 전송합니다.
 * [수정 사항] 제공해주신 라이브러리 예제에 맞춰 수정
 */
void sendSensorData() {
  int temperature = 0;
  int humidity = 0;

  // 온습도 값을 읽어 변수에 저장하고, 결과 코드를 반환받음
  int result = dht11.readTemperatureHumidity(temperature, humidity);

  // 결과 코드가 0이면 성공
  if (result == 0) {
    Serial.print("DATA: Temp=");
    Serial.print(temperature);
    Serial.print("C, Hum=");
    Serial.print(humidity);
    Serial.println("%");
  } else {
    // 라이브러리의 에러 문자열 출력 함수 사용
    Serial.print("Error: ");
    Serial.println(DHT11::getErrorString(result));
  }
}

/**
 * @brief 특정 주파수와 시간으로 부저를 울립니다.
 */
void playBuzzer(int frequency, int duration) {
  tone(BUZZER_PIN, frequency, duration);
}

/**
 * @brief 긴급 정지 인터럽트 핸들러.
 */
void handleEmergencyStop() {
  // 모든 동작 즉시 중지
  cleaningServo.write(90); // 서보모터 원위치
  digitalWrite(LED_PIN, HIGH); // LED를 켜서 상태 표시
  noTone(BUZZER_PIN);
  
  isEmergencyStopped = true;
  // 인터럽트 안에서는 Serial.println 사용을 피하는 것이 좋음
}

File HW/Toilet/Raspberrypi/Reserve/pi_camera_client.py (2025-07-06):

#!/usr/bin/env python3
# -*- coding: utf-8 -*-
"""
PI 카메라 기반 YOLOv11s 새똥 탐지 및 자동 청소 시스템
라즈베리파이 카메라 모듈 + GPIO UART 통신
"""

try:
    import serial
    import serial.tools.list_ports
except ImportError:
    print("pyserial 라이브러리가 설치되지 않았습니다.")
    print("다음 명령어로 설치하세요: pip install pyserial")
    exit(1)

try:
    from picamera2 import Picamera2
    import cv2
    import numpy as np
except ImportError:
    print("카메라 라이브러리가 설치되지 않았습니다.")
    print("다음 명령어로 설치하세요:")
    print("sudo apt install python3-picamera2")
    print("pip install opencv-python")
    exit(1)

try:
    from ultralytics import YOLO
except ImportError:
    print("YOLO 라이브러리가 설치되지 않았습니다.")
    print("다음 명령어로 설치하세요: pip install ultralytics")
    exit(1)

import json
import time
import threading
from datetime import datetime
from enum import Enum

class SystemState(Enum):
    """시스템 상태"""
    NORMAL = "정상 작동"
    WARNING = "알림 후 제한 모드"
    STOPPED = "정지 상태"

class BirdPoopDetector:
    def __init__(self, model_path="yolov11n.pt", confidence=0.5):
        """새똥 탐지기 초기화"""
        print("YOLOv11 모델 로딩 중...")
        self.model = YOLO(model_path)
        self.confidence = confidence
        self.target_coverage = 0.5  # 화면의 50% 커버리지
        print("YOLOv11 모델 로딩 완료!")

    def detect_bird_poop(self, frame):
        """프레임에서 새똥 탐지"""
        results = self.model(frame, conf=self.confidence, verbose=False)
        
        if not results or len(results) == 0:
            return False, 0.0, []
        
        frame_area = frame.shape[0] * frame.shape[1]
        total_detection_area = 0
        detection_boxes = []
        
        for result in results:
            boxes = result.boxes
            if boxes is not None:
                for box in boxes:
                    x1, y1, x2, y2 = box.xyxy[0].cpu().numpy()
                    box_area = (x2 - x1) * (y2 - y1)
                    total_detection_area += box_area
                    detection_boxes.append((int(x1), int(y1), int(x2), int(y2)))
        
        coverage_ratio = total_detection_area / frame_area
        is_detected = coverage_ratio >= self.target_coverage
        
        return is_detected, coverage_ratio, detection_boxes

class ArduinoClient:
    def __init__(self, port='/dev/ttyS0', baudrate=115200, timeout=1):
        """아두이노 클라이언트 초기화"""
        self.port = port
        self.baudrate = baudrate
        self.timeout = timeout
        self.serial_conn = None
        self.is_connected = False
        
    def connect(self):
        """아두이노에 연결"""
        try:
            self.serial_conn = serial.Serial(
                port=self.port,
                baudrate=self.baudrate,
                timeout=self.timeout
            )
            self.is_connected = True
            print(f"아두이노 연결 성공: {self.port}")
            return True
        except serial.SerialException as e:
            print(f"아두이노 연결 실패: {e}")
            return False
    
    def disconnect(self):
        """연결 해제"""
        if self.serial_conn and self.serial_conn.is_open:
            self.serial_conn.close()
            self.is_connected = False
            print("아두이노 연결 해제")
    
    def send_command(self, command, **kwargs):
        """아두이노에 명령 전송"""
        if not self.is_connected or self.serial_conn is None:
            print("아두이노가 연결되지 않았습니다.")
            return None
        
        cmd_data = {"command": command}
        cmd_data.update(kwargs)
        
        try:
            cmd_json = json.dumps(cmd_data) + '\n'
            self.serial_conn.write(cmd_json.encode('utf-8'))
            
            # 응답 대기
            response = self.serial_conn.readline().decode('utf-8').strip()
            if response:
                return json.loads(response)
            return None
            
        except Exception as e:
            print(f"명령 전송 실패: {e}")
            return None
    
    def get_sensor_data(self):
        """DHT11 센서 데이터 요청"""
        return self.send_command("get_sensor_data")
    
    def move_stepper(self, steps, speed=12):
        """스테핑 모터 이동"""
        return self.send_command("move_stepper", steps=steps, speed=speed)
    
    def stop_stepper(self):
        """스테핑 모터 정지"""
        return self.send_command("stop_stepper")
    
    def disable_stepper(self):
        """스테핑 모터 핀 비활성화 (전력 절약)"""
        return self.send_command("disable_stepper")
    
    def reset_stepper_position(self):
        """스테핑 모터 위치 초기화"""
        return self.send_command("reset_stepper_position")
    
    # === 새장 화장실 청소 시스템 기능들 ===
    
    def perform_cage_cleaning(self):
        """새장 화장실 청소 수행 (모래 밀어내기 + 스테핑 모터)"""
        return self.send_command("cage_cleaning")
    
    def activate_cleaning_servo(self):
        """청소 서보 작동 (모래 밀어내기)"""
        return self.send_command("activate_cleaning_servo")
    
    def reset_emergency_stop(self):
        """긴급 정지 해제"""
        return self.send_command("reset_emergency_stop")
    
    def reset_cleaning_cycles(self):
        """청소 횟수 초기화"""
        return self.send_command("reset_cleaning_cycles")
    
    def system_test(self):
        """시스템 테스트 (LED 깜빡임 + 부저 소리)"""
        return self.send_command("system_test")
    
    def get_system_status(self):
        """상세한 시스템 상태 정보 요청"""
        return self.send_command("get_status")
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

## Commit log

2025-06-29 아두이노 platform io 파일 생성
2025-06-29 YOLOV11 학습 환경 구축축
2025-06-29 pytorch.ipynb 파일 삭제
    [results.csv]
2025-06-30 dht11, dc 모터 제어 코드 추가
2025-07-06 화장실 기능 코드로 수정
    [main.cpp, pi_camera_client.py]
2025-07-06 아두이노 메모리 오류 수정정
    [main.cpp]
2025-07-06 화장실 기능 클린코드로 최적화 후 서보모터 추가
2025-07-06 arduino ram 초과 오류 수정정
    [main.cpp]
2025-07-06 SimAVR 테스트 완료 및 파일 정리
2025-07-06 주석 추가 및 함수 정리: 시리얼 입력 처리, 센서 데이터 전송, 명령어 유효성 검사 등 다양한 기능에 대한 주석을 추가하여 코드 가독성을 향상시킴.
2025-07-09 프로젝트 구조 정리: Toilet 기능 관련 자료들을 HW/Toilet 폴더로 통합
    - AI 폴더(YOLO 관련): HW/Toilet/AI/로 복사
    - Arduino 관련 자료: HW/Toilet/Arduino/로 이동
    - 라즈베리파이 관련 자료: HW/Toilet/Arduino/라즈베리파이/ 및 HW/Toilet/raspberry_pi_client.py로 이동
    - 화장실 기능 개발 관련 모든 자료를 한 곳에 체계적으로 정리
    [results.csv]
2025-07-09 파일 구조 정리리
2025-07-09 새똥탐지 모델 테스트 완료
    [pyvenv.cfg]
2025-07-12 앵무새 퍼즐 모델 학습 코드 작성
2025-07-12 앵무새 퍼즐 모델 학습 완료
    [Servo_ver.fzz, Toilet.fzz, results.csv]
2025-07-13 feat: 새똥 탐지 누적 시스템 및 쓰레기통 관리 기능 추가
2025-07-15 middle plate_team name
    [middle plate 07151235.stl]
2025-07-15 middle plate_teamname_07151320 Signed-off-by: rltgjqm02 <qkrwnsgk4@gnu.ac.kr>
    [middle plate_teamname_07151320.stl]
2025-07-16 아두이노 관련 코드 업데이트트
2025-07-16 시스템 동작 확인(서보모터 제외외)
2025-07-16 서보모터 부분 개선
2025-07-17 최적화 후 파일
2025-07-17 세부사항 수정정
2025-07-17 최종 화장실 코드 업로드드
2025-07-17 APP 환경 추가가
2025-07-17 APP 서버 연동 확인
2025-07-17 최종 화장실 코드
    [pyvenv.cfg]
